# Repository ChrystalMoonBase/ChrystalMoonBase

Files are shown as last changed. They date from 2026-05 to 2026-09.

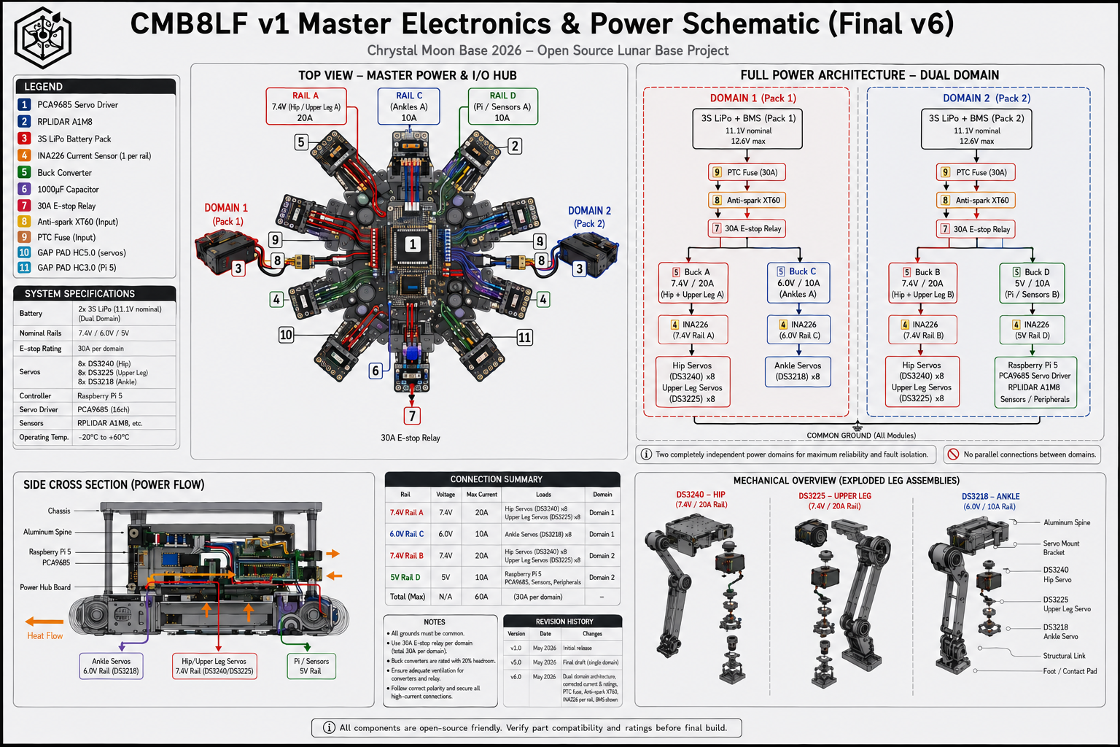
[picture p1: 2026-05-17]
systems/CMB8LF_v1/diagrams/CMB8LF-v1-Master-Schematic-Final-v6.png

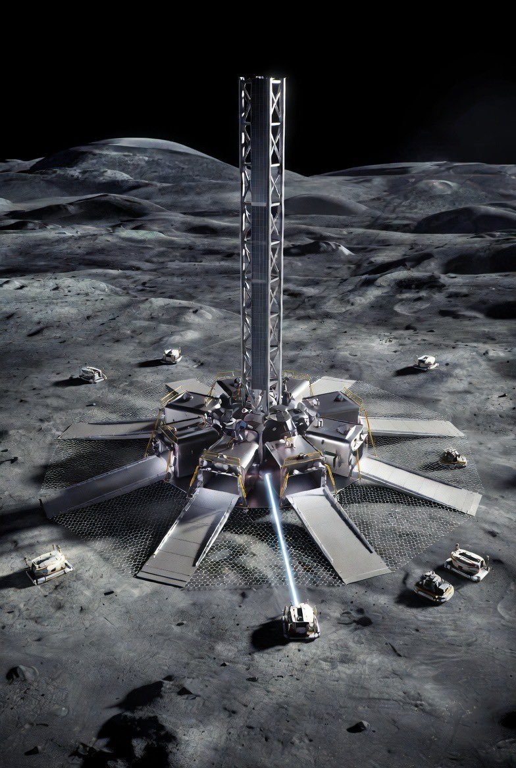
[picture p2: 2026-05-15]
public/assets/images/mastpod-render.png

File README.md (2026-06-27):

# Chrystal Moon Base
## Official Open-Source Repository

**A concept proposal for a permanent Moon base built from local lunar materials by autonomous robots.**
No flags. No patents. For all of humanity.

**Website:** https://chrystalmoonbase.com
**Licence:** Hardware: CERN-OHL-S-2.0 · Documents: CC0 · Software: Proprietary (not published)
**Status:** Phase 0 — Earth demonstrators (concept and planning stage)
**ESA OSIP:** Qualified — Open for Discussion · 2026

---

## What This Is

Chrystal Moon Base is an open-source concept for building a permanent human settlement on the lunar north pole (Peary Crater rim, 88.63°N) using:

- **Autonomous octopod robots** (CMB8LF-L1) — 16 robots powered by laser beamed from a ~35-metre solar mast
- **In-situ laser sintering** — fusing Peary highland regolith (anorthosite) into structural sintered glass-ceramic floors, walls, and dome foundations
- **600 m² roll-out CIGS solar system** — ~104–143 kW continuous power
- **Local material processing** — ~20 processing modules extracting glass, aluminium, oxygen, silicon, and (pending confirmed ice) water from the Moon
- **Multi-layer glass domes** — aluminium-reinforced, self-sealing habitats for permanent human residents
- **Maglev transport** — connecting all base facilities

> **Materials note:** Peary is highland / anorthosite terrain — aluminium-, silicon-, calcium- and oxygen-rich, but iron- and titanium-poor. Aluminium (not titanium) is the local structural metal. See `PEARY-MATERIALS-REFERENCE.md`.

---

## The Founder

**Berechja Kerkdijk**
Hegelsom, Limburg, Netherlands.
No PhD. No laboratory. No investors.
Just a man with a dream — researched and grounded in current science and technology.

---

## CMB8LF-S1 — Scale Prototype

The **CMB8LF-S1** (Chrystal Moon Base 8 Legged Freaks, version 1) is a 1:3.5 scale prototype of the CMB8LF-L1 lunar robot. It is the door that opens all other doors — a fully functional demonstrator that proves the concept physically.

**Key specifications:**
- 26× brushless BLDC motors with moteus r4.11 CAN controllers
- Distributed 22V power (25 independent battery nodes)
- Wave gait locomotion (maximum stability — 7 feet always grounded)
- Dual-laser palm: 808nm sinter + 976nm anneal (real glass powder sintering)
- 4-finger adaptive gripper: box grip / pincer / foot modes
- Bistable electromagnetic coupling (9 identical interfaces)
- All sensors in detachable head module
- Full vacuum compatibility (MoS₂ dry film · Si₃N₄ ceramic bearings · PEEK-CF)
- CAN bus internal · FSO laser communication external

**See:** `systems/CMB8LF_v1/`

---

## Repository Structure

```
foundation/
  governance/         CMB authority, tenant model, Earth relationship
  location/           Why Peary Crater — site selection and data
  philosophy/         Open-source principles, civilisation blueprint

media/                Pitch, technical, and vision one-pagers

roadmap/
  phase-0-earth/      Five Earth demonstrators (validation programme)
  phase-0.2-the-pod.md
  phase-1-foundation.md
  phase-2-the-city/
  phase-3-spaceport.md
  phase-4-beyond.md
  civilisation-blueprint/

systems/
  CMB8LF_v1/          ← Scale prototype robot (BUILD THIS FIRST)
    cad/              All 3D models (OpenSCAD) — open hardware
    docs/             BOM, assembly, shopping list
    diagrams/         Wiring, system overview
    (software is proprietary and kept in a separate private repository)
  robot-cmb8lf-l1/       Lunar robot concept specification
  sintering/          Laser sintering physics
  pod/                MAST-POD — mast, solar, laser, anchoring
  processing-modules/ All 13 resource extraction modules
  domes/              Habitat dome architecture
  life-support/       Atmosphere, water, food, radiation, gravity
  ai-and-monitoring/  Base AI, safety systems
  underground-network/Tunnels, maglev, emergency shelters
  surface-access/     Decontamination sequence

public/               Website source (chrystalmoonbase.com)
```

---

## Current Status

| Phase | Status |
|---|---|
| Phase 0 — CMB8LF-S1 prototype | **Active development** |
| Phase 0 — Earth demonstrators | Planning |
| Phase 0.2 — The Pod | Concept proposal |
| Phase 1+ | Long-term concept |

---

## How to Contribute

**Find an error:** Open a GitHub Issue.
**Improve a document:** Fork → edit → pull request.
**Build the prototype:** Follow `systems/CMB8LF_v1/README.md`
**You are an engineer:** Review the specifications. Find the problems. Say so clearly.

**Help us validate an open design question:** We are currently weighing an **integrated,
head-less robot** against the earlier **detachable-head** design, and we want engineering
input on whether we made the right call. See **`OPEN-DESIGN-INQUIRY-robot-head.md`**.

All contributors credited in `CREDITS.md`.

---

## Philosophy

The ISS proved that former rivals can build what neither could alone.
CERN proved that 23 nations can discover what one never would.
Chrystal Moon Base aspires to that same principle.

The Moon belongs to all of us.
This repository is our invitation to build it right.

---

## Contact

- **Email:** info@chrystalmoonbase.com
- **Website:** https://chrystalmoonbase.com
- **X:** [@chrystalbase](https://x.com/chrystalbase)

---

*No flags. No patents. No false promises.*
*Just a question worth asking honestly — and a Moon worth building together.*
🌙

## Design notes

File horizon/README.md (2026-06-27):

# CMB Horizon — speculative / far-future chapters

**Speculative / far-future chapters of Chrystal Moon Base.**
Deliberately separated from the hard CMB pillars (CMB8LF-S/L robots, MAST-POD, MRE
chain, gated-growth). Near-term feasibility is **not** claimed. Where something violates
a physical law, it is stated explicitly.

This folder collects the most exploratory CMB ideas. They are written to be *questioned
and corrected*, not believed. Two chapters so far:

1. **ISRU Cable Network & CMB8LF-B1 Tunnel-Mole** — linking the four Peary peaks.
2. **Hybrid Radiation Shielding (open question)** — could a superconducting magnet +
   passive layered dome ever help protect a habitat? Written as an honest open question;
   the most speculative item in the whole repo.

## Contents

```
horizon/
├── HORIZON_ISRU_cable_network.md          # chapter 1 (English, repo)
├── HORIZON_magnetic_shield_question.md     # chapter 2 — hybrid shield (THEORETICAL ONLY)
├── figures/
│   ├── mesh_overview.svg           # Fig.1 — 4 Pods + communication mesh
│   ├── worm_cross_section.svg      # Fig.2 — CMB8LF-B1 tunnel-mole, 2 zones
│   ├── electrical_schematic.svg    # Fig.3 — cable build-up + Pod-to-Pod line
│   └── factory_chain.svg           # Fig.4 — regolith→cable factory chain (F1-F4)
└── _werkversie_NL/                 # Dutch working copies (not for publication)
```

## Chapter 2 in one paragraph — Hybrid Radiation Shielding

Could an active superconducting magnet (bending charged cosmic-ray particles) paired with
a passive layered dome (catching the secondary neutrons the magnet cannot touch) ever
help shield a CMB habitat? The chapter establishes that this is a real, CERN/ESA/NASA
research line — but an **unsolved** one — and then honestly dismantles an earlier
over-optimistic draft: realistic dose reduction is **factor 2–3, not 99%**; the lunar
surface dose is ~380 mSv/yr (not 165); thick passive mass has **negative** returns past
~45 g/cm² due to secondary particles; YBCO (≈77 K) fits Peary's cold floors but MgB₂ does
not; and the ~20 GJ quench-protection problem is unsolved. The hybrid is the *right shape*
of an answer, but the specific numbers in the enthusiastic version did not survive
checking. Written explicitly as a question, inviting correction.

## Chapter 1 in one paragraph — ISRU Cable Network

The four *peaks of (near-)eternal light* on Peary's rim each carry an **energetically
independent Pod**. They are linked only for **communication/coordination** (not energy),
forming a self-healing mesh. This solves shadow downtime by *spreading locations*, with
no energy transported across the crater — which is physically impossible at the required
scale (130 kW over 100 km is 2–3 orders beyond the DARPA/China/Caltech state of the art;
diffraction is a physical law). Any cabling is made **on site** from regolith: aluminium
conductor (MRE/anorthite), glass/ceramic insulation (same regolith), laid underground by
the **CMB8LF-B1** — a new *Bore/Burrow* class robot that melt-bores a smooth glass duct
and lays the cable during production. One feedstock, three functions.

## Robot class registry

| Class | Meaning | Example | Status |
|---|---|---|---|
| S | Scale prototype | CMB8LF-S1 (1:3.5) | hard pillar |
| L | Lunar surface robot | CMB8LF-L1 (+ L1-Sinter/Dozer/Watcher) | hard pillar |
| **B** | **Bore / Burrow** | **CMB8LF-B1** (melt-boring tunnel-mole) | **HORIZON (speculative)** |

## Honesty note

This chapter is intentionally split into three feasibility categories:
**(1) impossible by physical law** (e.g. 100 km laser power beam),
**(2) possible but heavy/expensive** (e.g. hauling 100 km of cable from Earth),
**(3) possible and feasible** (e.g. ISRU cable + underground melt-bored duct).
All material/physics claims are sourced; see §10 of the main chapter.

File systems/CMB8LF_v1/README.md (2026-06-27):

# CMB8LF-S1 — Chrystal Moon Base 8 Legged Freaks
## Scale 1:3.5 · Vacuum-Rated · Brushless · CAN Bus · Full Revision v6

**Status:** Active development — build one leg at a time
**Author:** Berechja Kerkdijk
**Licence:** Hardware: CERN-OHL-S-2.0 · Software: Proprietary (separate private repo) · Docs: CC0

> **The prototype is the door.** Without a working robot, no door opens.
> Build it one leg per month. Two years if needed. But build it.

> **Parallel variant available.** A fully worked-out **head-less** version of this prototype
> exists at `../CMB8LF_v1_HL/` — same legs, same laser-palm, same brain, but with all sensing
> integrated into the body instead of a detachable head. It is kept build-ready so that if the
> open design question (`../../OPEN-DESIGN-INQUIRY-robot-head.md`) favours the head-less
> direction, no redesign is needed. This `CMB8LF_v1` folder remains the standard (with-head) build.

---

## What This Robot Does

- Walks on 8 legs using wave gait (7 always grounded — maximum stability)
- Sinters real glass powder / regolith simulant using dual lasers (808nm + 976nm)
- Grips objects in 3 modes: box grip · pincer · foot pad
- Operates in vacuum (MoS₂ dry film · ceramic bearings · no lubricants)
- Swaps its own legs with help from a second robot
- Communicates via laser (FSO) externally · CAN bus internally
- Runs 3-layer AI: Jetson Orin Nano strategic · Pico W coordination · RP2350 reflexes

---

## Specifications

| Parameter | Value |
|---|---|
| Scale | 1:3.5 |
| Legs | 8 (octopod) |
| Gripper legs | 2 (leg 1 + leg 2, front) |
| Joints | 26 (24 leg + 2 head) |
| Motors | 26× BLDC brushless |
| Motor controllers | 26× mjbots moteus r4.11 |
| System voltage | 22.2V (6S Li-Ion) |
| Battery nodes | 25 (distributed — one per segment) |
| Body battery | 4S 5000mAh LiPo |
| CAN bus speed | 1 Mbit/s |
| Gait | Wave gait (1 leg at a time) |
| Material structure | PEEK-CF |
| Bearing type | Si₃N₄ ceramic (vacuum-proof) |
| Lubrication | MoS₂ dry film only |
| Printer required | CreatBot PEEK-300 (primary) · Voron 2.4 + Rapido UHF or Intamsys FUNMAT HT (DIY alternatives) |
| Total cost estimate | ~€7.300 excl. printer |
| Build time | 10–14 months (one leg/month) |

---

## Build Order (one leg per month)

```
Month 1     Tools + printer + compute hardware
Month 2     Leg 3 (first standard leg — learn the system)
Month 3     Leg 1 (first gripper leg — laser palm)
Month 4     Leg 4
Month 5     Leg 2 (second gripper leg)
Month 6     Leg 5
Month 7     Leg 6
Month 8     Leg 7
Month 9     Leg 8
Month 10    Head module + all sensors
Month 11    Body + 9 coupling interfaces
Month 12+   Calibration · wave gait tuning · laser test · demo
```

---

## File Structure

```
CMB8LF_v1/
├── README.md               ← You are here
├── BOM_v6.md               ← Complete bill of materials
├── PRINT_SETTINGS.md       ← PEEK-CF print settings
├── VACUUM_PREP.md          ← Vacuum chamber preparation guide
├── SUPPLIER_MAILS_v6.md    ← Supplier contact templates
│
├── software/
│   ├── README.md
│   ├── main_v6.py          ← Pico W #1 — CAN master (start here)
│   ├── safety_pico.py      ← Pico W #2 — safety + web
│   ├── config_v6.py        ← All parameters and node IDs
│   ├── wave_gait_v6.py     ← Wave gait controller
│   ├── sinter_seq_v6.py    ← Laser sinter sequencer
│   ├── can_bus.py          ← CAN bus communication layer
│   ├── moteus_ctrl.py      ← moteus r4.11 controller interface
│   ├── rp2350_segment.py   ← Per-segment mini AI (runs on RP2350)
│   ├── laser_palm_v6.py    ← Laser palm driver (runs on palm RP2350)
│   ├── jetson_main.py      ← Jetson Orin Nano — strategic AI + navigation
│   └── web_v6.py           ← Web dashboard (runs on Pico W #2)
│
├── cad/
│   ├── CMB8LF_v1_vacuum_config.scad      ← Central dimensions (include first)
│   ├── CMB8LF_v1_leg_standard.scad       ← Standard leg (×6)
│   ├── CMB8LF_v1_leg_gripper.scad        ← Gripper leg (×2)
│   ├── CMB8LF_v1_palm_laser.scad         ← Laser palm assembly
│   ├── CMB8LF_v1_coupling_interface.scad ← Bistable magnetic coupling
│   ├── CMB8LF_v1_head_module.scad        ← Head with pan+tilt
│   ├── CMB8LF_v1_body_chassis.scad       ← Spider body
│   └── CMB8LF_v1_klipper_config.cfg      ← Printer config (Voron 2.4 DIY alt; CreatBot PEEK-300 uses its own slicer)
│
├── docs/
│   ├── CMB8LF_v1_BOM_vacuum.md
│   └── CMB8LF_v1_shopping_list.md
│
└── diagrams/
    ├── CMB8LF_v1_Wiring_Diagram.svg
    ├── CMB8LF_v1_Graphical_Overview.svg
    └── CMB8LF_v1_Lighting_Overview.svg
```

---

## I2C / CAN Bus Address Map

| Bus | Device | Address / Node ID | Notes |
|---|---|---|---|
| Jetson I2C | BNO055 IMU | 0x28 | Head |
| Jetson I2C | VL53L1X left | 0x29 | Head |
| Jetson I2C | VL53L1X right | 0x2A | Head |
| Jetson SPI | FLIR Lepton 3.5 | SPI0 | Head |
| Jetson UART | RPLIDAR A1M8 | UART | Head |
| Jetson CSI | Pi Camera 3 NoIR | CSI | Head |
| Jetson USB | USB-CAN (Canable) | — | CAN master |
| CAN | Leg 1 coxa moteus | Node 11 | Gripper leg L |
| CAN | Leg 1 femur moteus | Node 12 | Gripper leg L |
| CAN | Leg 1 tibia moteus | Node 13 | Gripper leg L |
| CAN | Leg 2 coxa moteus | Node 21 | Gripper leg R |
| CAN | Legs 3-8 | Node 3X-8X | Standard legs |
| CAN | Head pan moteus | Node 91 | Head |
| CAN | Head tilt moteus | Node 92 | Head |
| Pico W #2 I2C | INA226 ×4 | 0x44-0x47 | Power monitoring |
| Pico W #2 I2C | TMP117 body | 0x48 | Body temp |
| Pico W #2 GPIO | Hall sensors ×9 | GPIO 0-8 | Coupling status |

---

## Safety Rules — Always

1. **OD4+ laser goggles** rated for 808nm AND 976nm — always when lasers could activate
2. **E-stop button** within reach at all times during operation
3. **Never power lasers** unless gripper closed (hardware interlock enforces this)
4. **Never walk and sinter** simultaneously — these are separate modes
5. **MoS₂ only** — never oil, grease, or wet lubricant anywhere on the robot

---

## License

- Hardware designs: CERN-OHL-S-2.0
- Software: Proprietary — kept in a separate private repository (see `LEGAL-STRUCTURE.md` and `software/README.md`)
- Documentation: CC0

*CMB8LF-S1 · CC0 2026 · Chrystal Moon Base · No rights reserved*
*Multi-AI: Claude · ChatGPT · Meta · DeepSeek · Gemini · Human decisions: Berechja Kerkdijk*

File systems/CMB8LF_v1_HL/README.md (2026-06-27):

# CMB8LF-S1-HL — Head-Less Scale Prototype (parallel variant)

**Status:** Complete parallel design, ready to build if selected
**Author:** Berechja Kerkdijk
**Licence:** Hardware: CERN-OHL-S-2.0 · Software: Proprietary (separate private repo) · Docs: CC0

> **What this is.** A fully worked-out **head-less** version of the CMB8LF-S1 prototype,
> built and documented *in parallel* with the standard head variant (`../CMB8LF_v1/`). It
> exists so that, if the open design question in `OPEN-DESIGN-INQUIRY-robot-head.md` resolves
> in favour of the integrated/head-less direction, the build is **already finished** — schematics,
> CAD, BOM, firmware and all — and no months of redesign are needed. The decision becomes
> "pick variant A or B," not "now start designing B."

---

## The one difference

This variant changes **only the sensing/camera layer**. Everything else is identical to the
standard prototype:

| Subsystem | Standard `CMB8LF_v1` | This head-less `CMB8LF_v1_HL` |
|---|---|---|
| Sensors / cameras | In a **detachable front head** (pan/tilt module between leg 1 & 2) | **Integrated into the body** — work-sensing between the front legs + 360° awareness ring + override cameras. No head, no pan/tilt. |
| Working laser (sinter) | **In the front-leg palm** | **In the front-leg palm — UNCHANGED** |
| Legs (standard + gripper) | 8 legs, 3 DOF each | **Identical — shared** |
| Chassis / body shell | Spider PEEK-CF, 9th coupling = head | Spider PEEK-CF, **9th coupling removed/blanked**; sensor recesses added |
| CAN bus / moteus / motors | 26× RP2350, Pico W ×2, moteus | **Identical — shared** |
| Compute (brain) | Jetson Orin Nano in body | **Identical — shared (Jetson in body)** |
| Power / battery | Distributed rail | **Identical — shared** |
| Gait / kinematics | Wave gait, encoder-based | **Identical — shared** |

**Because only sensing changes, this variant does not duplicate the shared subsystems.** Where
a file would be byte-for-byte identical to the standard prototype, this folder **references the
shared base** instead of copying it — so the two variants cannot silently drift apart. Only the
files that genuinely differ are fully written out here.

---

## Files in this variant

**Fully worked out here (they differ):**
- `docs/HEADLESS_DESIGN.md` — the complete sensor-relocation design: what moves where, why,
  and how each sensor is protected.
- `CMB8LF_v1_HL_BOM.md` — full bill of materials (delta-marked against the standard BOM).
- `cad/CMB8LF_v1_HL_body_chassis.scad` — body shell with integrated sensor recesses and the
  9th (head) coupling blanked.
- `cad/CMB8LF_v1_HL_sensor_mounts.scad` — the new body-integrated sensor/camera mounts
  (replaces `head_module.scad`).
- `cad/CMB8LF_v1_HL_config.scad` — variant dimension overrides (sensor positions, recess sizes).
- `diagrams/CMB8LF_v1_HL_Wiring_Diagram.svg` — wiring for the relocated sensors/cameras.
- `diagrams/CMB8LF_v1_HL_Sensor_Layout.svg` — top/side view of where every sensor sits on the body.
- `software/sensors_headless.py` — sensor manager for the body-integrated layout + override feed.
- `software/config_headless.py` — pin map / sensor addresses for this variant.

**Shared with the standard prototype (do NOT duplicate — use the base files):**
- All leg CAD: `../CMB8LF_v1/cad/CMB8LF_v1_leg_*.scad`, `arm_leg_combined.scad`, `coupling_interface.scad`, `palm_laser.scad`
- All motion/control firmware: `../CMB8LF_v1/software/{gait,leg,moteus_ctrl,can_bus,rp2350_segment,safety,servo,wave_gait_v6}.py`
- Laser-palm firmware: `../CMB8LF_v1/software/laser_palm_v6.py`, `palm_spectroscopy.py`
- Print settings: `../CMB8LF_v1/PRINT_SETTINGS.md`, `CMB8LF-v1-PRINT_SETTINGS.md`
- Vacuum prep: `../CMB8LF_v1/VACUUM_PREP.md`
- Shared dimensions: `../CMB8LF_v1/cad/CMB8LF_v1_vacuum_config.scad` (this variant's config *includes* it and only overrides what changes)

---

## Why keep the laser-palm in the leg (unchanged)

The working laser stays in the front-leg palm exactly as in the standard build. This is
deliberate: the arm-legs already bring the laser precisely to the work point using
encoder-based positioning, and the palm already carries the close-range sinter/melt optics
and the palm spectroscopy. Moving the laser would change the proven leg design for no benefit.
The head-less change is *only* about where the **sensors and cameras** live — not the tool.

---

## Relationship to the L1 concept

This is the **scale prototype** expression of the head-less direction discussed for the
full-size L1 robot in `../robot-cmb8lf-l1/chassis.md` and `OPEN-DESIGN-INQUIRY-robot-head.md`.
Building it at prototype scale is how we test whether body-integrated sensing actually works
for precise close-up sinter/melt work before committing the lunar design.

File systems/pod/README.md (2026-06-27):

# Pod — Anchor System

**Chrystal Moon Base · Phase 0.2**
**Status:** Concept proposal — open question, not a flight specification.
**Licence:** CC0

---

## Selected design: Rooted Hybrid (v2.5)

The anchoring problem — how to attach a ~35-metre telescoping mast permanently to the lunar surface — was evaluated across four candidate concepts. After analysis, the **Rooted Hybrid** was identified as the strongest practical baseline.

**→ [mast-anchor-rooted-hybrid.md](./mast-anchor-rooted-hybrid.md) — canonical anchor specification**

### Why Rooted Hybrid

Three design principles make it the most defensible choice:

**Immediate stability** — A central titanium penetrator (120–150 kg) drives 0.5–0.8 metres into the regolith at landing. No waiting. The structure is mechanically locked from the first seconds.

**Permanent bonding** — Sintered regolith root plugs and beams, produced by the CMB8LF-L1 robots using the mast's own laser, chemically and mechanically fuse the anchor to the regolith over 6–8 weeks. Unlike pure mechanical anchors, this cannot loosen.

**Layered redundancy** — Neither the mechanical penetrator nor the sintered roots depends entirely on the other. If one system is weaker than expected due to regolith variability, the other provides backup. This is how serious aerospace structures are designed.

### Key open questions

| Question | Status |
|---|---|
| Regolith bearing capacity at Peary rim (88.63°N) | Requires Phase 0 ground testing |
| Sintering energy 8000 kWh/m³ — scalability to 0.25 m depth | Needs simulation + physical test |
| TRN landing precision — 26.5 m target zone on specific ridge | Engineering verification needed |
| Articulated shell segment reliability after cold soak at −150°C | Material and mechanism testing required |

---

## Archived alternatives

Three alternative anchor concepts were fully documented before the Rooted Hybrid was selected. They are preserved in full — not deleted — because the comparison itself is evidence of rigorous evaluation.

**→ [archive/](./archive/) — Spike, Pure Bloom, Adaptive Bloom**

The archive README explains the tradeoffs that led to the Rooted Hybrid selection.

---

## Files in this directory

| File | Description |
|---|---|
| `mast-anchor-rooted-hybrid.md` | **Canonical anchor design — use this** |
| `mast-overview.md` | Mast and solar curtain system description |
| `archive/` | Three evaluated-and-archived alternative anchor concepts |

---

**Repository:** [github.com/ChrystalMoonBase/ChrystalMoonBase](https://github.com/ChrystalMoonBase/ChrystalMoonBase)
**Contact:** info@chrystalmoonbase.com

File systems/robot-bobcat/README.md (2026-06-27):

# CMB Bobcat — Robotic Excavator / Dozer

> **Status:** concept. Role is concrete; exact dimensions, mass, and power are
> engineering decisions for professionals once real excavation volumes and the prototype
> are known. This document fixes *what it is and why*, not the final numbers.

> **Naming note:** a clean, plate-style code (type instantly readable from the code) will
> be assigned later when the whole robot family is renamed. For now: "CMB Bobcat".

---

## Role: the digger and ground-mover

The Bobcat is a **dedicated earth-moving machine** — a robotic equivalent of a compact
Bobcat-style loader. It does the two heavy ground tasks that are fundamentally different
from the octopod's "stand still and sinter" work:

- **Excavating** — digging trenches, foundations, the underground network, and
  (contingent on confirmed ice) ice-bearing regolith.
- **Dozing / grading** — pushing and levelling loose regolith, preparing flat ground for
  the octopods to sinter on.

Digging and pushing require **traction and brute force in one direction**, a completely
different body from a robot that must hold an eight-point stance to weld. That physical
difference — not specialisation for its own sake — is why the Bobcat is its own class.

---

## Why a separate machine (not an octopod tool-swap)

The octopod (CMB8LF) is a work platform: it must stand rock-still on uneven ground while a
laser arm does precision work. Excavation is the opposite — it needs to **drive force into
the ground** and move material in volume. Trying to do that on eight legs built for
stillness would compromise both tasks. The Bobcat is therefore a different *body for a
different physical reality*, the same logic that gives the transport bot and the cable-worm
their own forms. The "no specialists" principle still holds **within** the construction
fleet of octopods; the Bobcat is a different class, not a fourth specialist octopod.

---

## Locomotion: tracks, not legs (likely)

Excavators on Earth use tracks for a reason: they spread weight, grip loose ground, and
resist the reaction forces of digging. On loose lunar regolith and slopes, tracks are the
strong candidate — but wheels-on-frame or a hybrid are not ruled out. **Final locomotion
choice is for the professionals**, tested against real regolith behaviour. What is fixed:
it does not walk; it drives and pushes.

---

## How it fits the fleet

- **Works ahead of the octopods:** the Bobcat prepares and levels ground; the octopods
  then sinter it. Natural task ordering.
- **Feeds the ISRU chain:** excavated regolith is raw feedstock for the processing
  modules.
- **Shares the canister standard** (see transport-bot): excavated material can be loaded
  into standard canisters for the transport bot to move.
- **Redundancy by number, within its own class:** like the octopods, the answer to "what
  if one fails" is more than one — not in-field electronics repair.

---

## When it is needed (timeline)

- **Not strictly day one.** The very first task is the octopods proving they can walk and
  sinter (the swarm foundation). Heavy excavation comes once surface work is underway and
  the base goes underground.
- **Early, though:** ground levelling helps the octopods sinter sooner, so a Bobcat is an
  early-growth addition rather than a far-future one.

---

## Specifications — for the professionals

The following are deliberately **not fixed** here; they require excavation-volume data,
mass-budget analysis, and prototype testing:

- Size, mass, and track/drive design
- Digging force, bucket/blade volume, reach
- Power draw and how it is fed (laser beaming like the octopods? onboard? hybrid?)
- Thermal handling under sustained heavy load
- How many Bobcats per fleet (depends on total excavation workload)

What is fixed: **role** (dig + doze), **why separate** (force vs. stillness), **fleet
fit** (works ahead of octopods, feeds ISRU, shares canisters), and **redundancy by
number**.

---

## Open questions

1. Tracks vs. wheels vs. hybrid on real Peary regolith and slopes?
2. Power: beamed (like octopods) or onboard? Heavy continuous digging is power-hungry.
3. Does it also load canisters, or only loosen/push material for others to load?
4. How much of the octopod's proven subsystems (sensors, comms, autonomy stack) can it
   reuse to avoid designing a second robot from scratch?

*Engineers and mission planners are invited to review and improve this document.*

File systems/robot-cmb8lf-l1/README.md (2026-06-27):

# CMB8LF-L1 — Autonomous Octopod Construction Robot

**Chrystal Moon Base · Phase 0.2**
**Status:** Concept proposal — no prototype exists. Open question, not a specification.
**Kinematic reference:** [Robugtix T8](https://www.robugtix.com) — 8 legs, 3 DOF/leg, verified platform
**Licence:** CC0 (documents) · CERN-OHL-S-2.0 (hardware designs)

---

## Design philosophy: sixteen identical, fully capable

There are no specialists. There is no dependency between robots. Every CMB8LF-L1 is identical to every other CMB8LF-L1, and every CMB8LF-L1 can do everything.

This is not a choice driven by elegance. It is driven by reliability. On the Moon there is no repair crew. With sixteen identical chassis, loss of one robot means loss of one-sixteenth of capacity — nothing more. The other fifteen continue unchanged.

---

## Key specifications

| Parameter | Value | Notes |
|---|---|---|
| Mass | ~300 kg | Estimated |
| Legs | 8 × 3-DOF | T8 kinematic architecture |
| Configuration | 6 stance · 2 arm-legs | Front pair — each carries a separate module |
| Foot type | Snowshoe flat plate | 400 × 150 mm — no sinkage in 1/6 g regolith |
| Frame | Ti-6Al-4V | Titanium alloy structural skeleton |
| Armour | Mineral fibre (anorthosite) + MgAl2O4 ceramic | Multi-layer thermal and impact protection |
| Power | Laser beaming | GaAs PV receiver, quadrant beam tracking |
| Battery | Solid-state LiPON | One cell per leg segment — local motor power |
| Left arm module | Sintering laser | 10-20 cm compact unit, EPM-swappable |
| Right arm module | W-Re alloy forming tip | Direct regolith shaping, EPM-swappable |
| Heavy tool interface | EPM electropermanent magnet | less than 5 W pulse to lock, 0 W to hold |
| Temperature range | -180C to +130C | Full Peary crater rim operational envelope |
| AI system | Triple Modular Redundancy TMR | Fault-tolerant autonomous control |
| Degraded mode | 5-leg gait | On single leg failure — no mission abort |
| Dust sealing | Triple-ring brush NiC fibre | All joints and rotation interfaces |

---

## The two-arm system: melt and form

This is the core of what the CMB8LF-L1 does. Two arm-legs. Two functions. One continuous motion.

### Left arm — laser module

A compact laser unit (10-20 cm) connects to the left arm-leg via EPM. It melts lunar regolith to approximately 1100-1200 degrees C. The laser module is a swappable unit: if it fails, the robot walks to the tool rack, disconnects the old module, picks up a spare, and resumes in minutes.

### Right arm — W-Re forming tip

A tungsten-rhenium alloy tip connects to the right arm-leg via EPM. While the left arm melts the surface, the right arm presses, shapes, and holds the molten regolith as it cools from ~1200C toward ~800C. The result is a formed, smooth, solid surface.

In vacuum there is no convective cooling. Molten regolith in lunar vacuum cools significantly slower than on Earth, giving the forming tip time to work. At forming temperature its viscosity is comparable to thick syrup — a few newtons of steady pressure is enough to shape it. (Viscosity/temperature figures here are basalt-referenced; see the feedstock note below.)

This is, in essence, robotic glassblowing on the Moon — with melted regolith (anorthosite).

> **Feedstock note:** The ~1,200 °C figure is *basalt-referenced* (from published experiments and simulants). The actual Peary feedstock is highland anorthosite, which melts hotter (~1,550 °C), raising laser-energy demand and tightening forming-tip and cooling margins. See `systems/sintering/laser-sintering-physics.md` → "Melt Temperature — Basalt versus Highland Anorthosite".

**Why W-Re:**

| Property | Value | Significance |
|---|---|---|
| Melting point | above 3000C | Safe margin over molten regolith (~1,200 C basalt-ref / ~1,550 C anorthosite) |
| Ductility | W-25%Re: significantly higher elongation than pure W | Survives arm-leg impact loads without fracture |
| Magnetic | Non-magnetic | Does not attract electrostatically charged lunar dust |
| Chemical stability | No oxidation below 500-600C | In lunar vacuum: zero oxidation |
| Surface coating | HfC melting point 3958C | Reduces molten-regolith adhesion to the tip |

**Thermal isolation:** A ceramic thermal break (aerogel + ZrO2 standoffs) sits between the W-Re tip and the Ti-6Al-4V arm structure.

### If a module fails: detach and replace

Both the laser module and the W-Re forming tip connect via the same EPM interface. If either fails:

1. Robot walks to the tool rack
2. EPM pulse — module detaches
3. Robot picks up spare module from rack
4. EPM pulse — locked
5. Robot resumes

No other robot needed. No mission pause. Spare inventory: laser modules, W-Re tips, bulldozer blades, digger tools — all in the same rack, all using the same EPM interface.

### Two robots working together

One robot can operate both arms on a single patch. Two robots can also collaborate: one melts with its left arm while the second forms with its right arm on the same surface. This doubles throughput on critical sections and provides natural redundancy.

---

## All sensors integrated in the chassis

No sensor specialist. Every CMB8LF-L1 carries the full suite permanently:

- Terrain scanner — continuous surface mapping
- Temperature sensors — monitoring sintered surface temperature in real time
- Beam tracking photodiode — quadrant sensor for laser power alignment at 100 Hz
- Structural load sensors — in each leg segment
- Stereo cameras — on the main body

---

## Stability during arm operation

Six stance legs hold the robot steady while both arm-legs work.

**Snowshoe feet** — 400 x 150 mm flat plates distribute ground pressure. No sinkage even under arm reaction forces in 1/6 g regolith.

**Six-leg positioning** — 3 DOF per leg. All six splay wide, lower the centre of mass, and pre-load before arm contact.

**W-Re tip geometry** — the forming tip presses with controlled, predictable force. The HfC coating prevents sticking. The arm releases cleanly at any point in the forming cycle.

---

## Heavy tool operations (EPM-swapped)

When the robot needs to move large volumes of loose regolith or excavate tunnels, it swaps one or both arm modules for heavy tools:

- **[Bulldozer blade](./tools/bulldozer-blade.md)** — Al-Mg-Sc, 1.2 m x 0.4 m
- **[Digger tool](./tools/digger-tool.md)** — counter-rotating bucket drums (Phase 1.2+)

The swap is the same motion as swapping a laser module or forming tip. Walk to rack, EPM pulse, walk away.

---

## What this replaces

**Previous concept (archived):** Four specialist robot types — melter, all-rounder, temperature buddy, bulldozer. Specialist dependency.

**Current concept:** Sixteen identical chassis. Left arm melts. Right arm forms. EPM swaps anything. Nothing depends on a specialist.

---

## Open questions

| Question | Why it matters |
|---|---|
| Does molten regolith (anorthosite) adhere to HfC-coated W-Re? | Core feasibility of the forming tip |
| Optimal W-Re tip geometry for molten-regolith shaping | Flat press? Curved blade? Requires physical test |
| Thermal break performance under -150C to +1200C cycling | Ceramic standoffs must survive repeated thermal shock |
| Laser module thermal management in arm-leg | Heat routing within confined arm structure |
| Molten regolith cooling rate in lunar vacuum | Determines working window for the forming tip |
| LiPON battery after repeated thermal cycling | Leg segment power reliability |
| Sintering energy nominal 8000 kWh per cubic metre | Most uncertain number in the entire system |
| Regolith bearing capacity at Peary rim | Determines leg stance force limits |

---

## Directory structure

```
systems/robot-cmb8lf-l1/
├── README.md                         <- this file
├── tools/
│   ├── README.md                     <- EPM interface and spare parts
│   ├── bulldozer-blade.md
│   └── digger-tool.md
└── reference/
    └── kinematic-reference-t8.md
```

---

**Repository:** github.com/ChrystalMoonBase/ChrystalMoonBase
**Contact:** info@chrystalmoonbase.com

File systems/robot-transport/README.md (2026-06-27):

# CMB Transport Bot — Robotic Hauler

> **Status:** concept. Role is concrete; exact dimensions, mass, payload, and power are
> engineering decisions for professionals once real cargo volumes and the prototype are
> known. This document fixes *what it is and why*, not the final numbers.

> **Naming note:** a clean, plate-style code (type instantly readable from the code) will
> be assigned later when the whole robot family is renamed. For now: "CMB Transport Bot".

---

## Role: move (almost) anything from A to B

The transport bot is a **dedicated hauler**. Once the base starts producing and growing,
material has to be moved: sintered components, excavated regolith, harvested modules from
dead robots, spare parts from the garages, ice-bearing material, ISRU feedstock between
factories. The octopods *can* drag loads in a pinch, but they are work platforms, not
movers — hauling over the base's own (already sintered) flat paths is a different task.

Over prepared, sintered paths, **wheels are the logical choice** — exactly the point made
in the "why legs, not wheels" discussion: wheels are perfect for rolling over prepared
ground, which is precisely what the transport bot does. It does not work on loose slopes;
it runs on the roads the octopods have already laid.

---

## The key idea: a standard canister

The transport bot is designed around a **standard canister / container**, not around any
single cargo type. This is the shipping-container principle applied to the Moon:

- Everything that needs moving goes into the **same standard canister format**.
- The transport bot does not need to know *what* it carries — only *how to couple a
  canister*.
- The same canister can be handled by the **transport bot, the octopods, and the Bobcat**
  — one shared interface across the whole fleet.

Just as standard containers transformed logistics on Earth (one size, and suddenly
everything fits every truck, ship, and crane), a single canister standard means any
machine can pick up any load. This is the transport bot's most important design decision —
arguably more important than the bot's own body.

---

## Why a separate machine (not an octopod tool-swap)

Hauling cargo efficiently over flat sintered paths is a different physical job from
standing still to sinter. Wheels + a canister coupling are simpler, lighter, more
energy-efficient, and stable enough for this task — where the octopod's eight legs would
be overkill. Different body for a different physical reality; the "no specialists"
principle holds within the octopod construction fleet, and the transport bot is a separate
class.

**Fallback safety:** if every transport bot were to fail, the octopods can still haul
loads themselves (slower, less efficient). So the transport class makes the base *more
efficient* but is not a hard single-point dependency — the construction class can fall
back on itself.

---

## How it fits the fleet

- **Runs on octopod-built roads:** transport follows construction. It needs sintered flat
  paths, which the octopods produce as they work.
- **Connects the chain:** Bobcat excavates → canister → transport bot moves it → ISRU
  module or build site. The canister standard ties it together.
- **Redundancy by number, within its own class.**

---

## When it is needed (timeline)

- **Not day one.** Early on there is little to move and few paths to move it over. The
  swarm foundation (octopods walking and sintering) comes first.
- **Grows in with the base:** as sintered paths and production volume appear, the
  transport bot becomes worthwhile. A growth-stage addition.

---

## Specifications — for the professionals

Deliberately **not fixed** here; they require cargo-volume data, mass-budget analysis, and
prototype testing:

- Size, mass, wheel/drive design, payload capacity
- The exact canister standard (dimensions, coupling mechanism, how it locks)
- Power draw and how it is fed (beamed / onboard / hybrid)
- How many transport bots per fleet (depends on cargo workload and path network size)

What is fixed: **role** (haul anything via standard canisters), **wheels over sintered
paths**, the **canister standard as the core idea**, **fleet fit**, and **octopod
fallback**.

---

## Open questions

1. Canister dimensions and coupling: what single standard serves regolith, parts,
   modules, and ice equally well?
2. Power over distance: beamed power works near the mast; long hauls may leave beam range
   — onboard battery, swappable canister-batteries, or path-side charging?
3. Does the transport bot self-load, or do octopods/Bobcat load the canisters onto it?
4. How much of the octopod's proven subsystems (sensors, comms, autonomy) can it reuse?

*Engineers and mission planners are invited to review and improve this document.*

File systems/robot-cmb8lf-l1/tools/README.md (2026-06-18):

# CMB8LF-L1 Tool Interface — EPM Standard & Spare Parts

**Chrystal Moon Base · Phase 0.2**
**Licence:** CC0

---

## What the EPM rack holds

Every CMB8LF-L1 tool — including the arm modules themselves — connects via the same EPM interface. The rack in each garage holds everything:

| Item | Type | Phase | Purpose |
|---|---|---|---|
| Sintering laser module | Arm module (left) | 0.2 | Melts regolith to ~1200C |
| W-Re forming tip | Arm module (right) | 0.2 | Shapes and smooths molten regolith |
| Bulldozer blade | Heavy tool | 0.2 | Grades loose regolith |
| Digger tool | Heavy tool | 1.2+ | Excavates underground tunnels |

Spares of the laser module and W-Re tip are stored alongside the heavy tools. Same rack. Same EPM connection. Same swap procedure.

---

## The EPM interface

| Parameter | Value |
|---|---|
| Activation energy | less than 5 W for less than 1 second |
| Hold power | 0 W — permanent magnet holds without power |
| Release energy | less than 5 W for less than 1 second |
| Moving parts | None |
| Fail mode | Locked — module cannot accidentally drop |

---

## Swap procedure (any module)

1. Robot walks to tool rack
2. EPM pulse — module detaches
3. Robot aligns arm-tip to replacement module on rack
4. EPM pulse — locked
5. Robot resumes work

No second robot. No human. No mission pause.

---

## Two-arm operation

The two arm-legs operate independently. In standard sintering mode:

- **Left arm:** laser module active — melts the surface
- **Right arm:** W-Re forming tip active — presses and shapes the melt

When heavy physical work is needed, one or both arm modules are swapped for the blade or digger. The laser and forming tip go back on the rack while the heavy tool is in use. When the grading or excavation is done, the robot picks its arm modules back up.

---

## What is NOT an EPM swap

All sensors (terrain scanner, temperature sensors, cameras, photodiodes, structural load cells) are permanently integrated into the chassis body. They never swap. They never go on the rack.

---

## Compatibility

The W-Re forming tip and the sintering laser module both use the same EPM mounting geometry. A robot with two forming tips or two laser modules is mechanically possible — though the standard configuration is one of each.

---

**Parent:** [../README.md](../README.md)
**Repository:** github.com/ChrystalMoonBase/ChrystalMoonBase

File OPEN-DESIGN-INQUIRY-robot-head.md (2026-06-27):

# Open Design Inquiry — Does the robot need a "head" at all?

**Status: active design direction, seeking engineering validation.**
**We are taking the lead with an integrated (head-less) concept, but we are explicitly
asking: did we make the right call, or should we step back to the detachable-head design?**

This is a question-led document in the spirit of the project: we would rather show the
open question honestly and invite correction than present a frozen decision. If you are an
engineer reading this — robotics, field robotics, space hardware, autonomy — your input on
this specific trade-off is genuinely wanted.

---

## The question in one line

Should each CMB8LF robot have a **distinct sensor head** (mounted at the front, detachable
like a leg), or should we **drop the head entirely** and integrate everything into the
body + legs?

---

## How we got here

The earlier design gave each robot a **head**: a front-mounted unit (spider position),
carrying the sensors and the working-laser optics, attached through the same universal EPM
coupling as the legs — so it could be swapped or harvested like a leg. (See the "Previous
concept" note in `systems/robot-cmb8lf-l1/chassis.md` and the `head-*.md` files.)

While reviewing the design we questioned a basic assumption: *is a "head" a real
engineering need, or is it a human/animal image we projected onto a machine?* A spider's
head is not a detachable add-on — it is fused with the body. A self-driving car has no
head — its sensors are distributed around the chassis. That reframing led to the current
direction.

---

## The direction we are now taking (and want validated)

**Drop the separate head. Integrate sensing into the body and legs.** Concretely:

1. **No detachable head.** Body + legs as one unit, like a real spider. This removes a
   coupling that can fail, a moving part, a dust-entry point, and a component that can be
   lost.

2. **The brain stays deep in the body.** Critical compute (the Jetson-class strategic AI)
   lives in the protected three-layer body core, never in an exposed, moving part. Putting
   costly hardware in the most exposed place would raise its failure rate and lose it if
   that part is damaged.

3. **"Measuring" is not "seeing."** For autonomous work the robot does not need eyes:
   - It knows where its arm-legs are from **joint encoders** (proprioception), not from
     looking at them.
   - It knows whether a sinter/melt is good from **thermal + spectroscopic measurement**,
     not from a camera view.
   - It builds a spatial map from **LiDAR / ranging**, not from human-style vision.

4. **Two distinct sensing needs, separated by function:**
   - **Targeted work-sensing — between the front legs.** Where the arm-legs do the
     sinter/melt work, downward/forward-looking measurement sensors watch the work zone
     directly.
   - **360° awareness — around the body.** Distributed fixed sensors around the chassis
     give all-round situational awareness (navigation, obstacles, other robots). No single
     moving head can cover 360° at once; distributed sensors can.

5. **A live camera feed is still required — but for the human, not the robot.** Every
   robot must support **override by a CMB engineer**. A human cannot override on encoder
   angles and spectra alone; they need a human-interpretable image. So each robot carries
   camera(s) feeding the work zone **plus** surrounding cameras, so an engineer can assess
   the whole situation before acting. Because of the ~2.6 s round-trip delay, this is for
   **situation assessment and re-tasking, not real-time joysticking** — which lowers the
   feed's latency requirements.

---

## What this buys us, and what it costs

**Gains:** fewer failure points (no head coupling, no head-swap mechanism), no
head-as-moving-part, better-than-a-head 360° coverage from distributed sensors, brain kept
in the safest place, lighter and simpler front end.

**Costs / things we give up or must solve:**
- We lose a *detachable* head that could be harvested from a dead unit. (Legs and
  arm-modules remain harvestable; is that enough redundancy?)
- Sensors that used to sit on a movable head are now fixed — we rely on distributed
  coverage + the robot turning its body instead of panning a head.
- **Open sub-question (unsolved):** the work-sensing between the front legs looks straight
  at intense heat, laser glare, and out-gassing/spatter from the melt zone — the most
  hostile spot for a sensor. How best to protect it (replaceable/closable window, oblique
  off-axis mounting, time-sharing while the laser is at full power)? We have deliberately
  **not** fixed this yet.

---

## The validation question for engineers

We are asking, plainly:

1. **Is dropping the head the right call** for a field robot doing autonomous lunar
   sinter/melt construction — or are we over-rotating on "no human assumptions" and
   throwing away a genuinely useful degree of freedom?
2. **Is encoder-based proprioception + distributed fixed sensing** truly sufficient for
   this kind of precise, close-up manipulation work, or does practice demand an
   articulated sensor platform after all?
3. **How would you protect the work-zone sensor** facing the melt? (The open sub-question
   above.)
4. If you would **step back to the detachable head**, what is the deciding reason?

Honest "you got this wrong because…" answers are the most useful kind. The full design is
open (`github.com/ChrystalMoonBase`, `chrystalmoonbase.com`); hardware under CERN-OHL-S-2.0,
docs under CC0.

> **Note:** the head-less direction is not just a sketch — a **complete parallel prototype
> variant** is already worked out at `systems/CMB8LF_v1_HL/` (BOM, CAD, schematics, firmware).
> So whichever way this resolves, the build is ready: it is a choice between two finished
> designs, not a request to start designing the alternative.

---

*This document records a design direction under active consideration. It is intentionally
not yet propagated into the full build documents; `chassis.md` now leads with the
integrated concept and references the superseded detachable-head design, but the older
`head-*.md` files are retained (with superseded banners) so the full history of the
decision stays visible.*

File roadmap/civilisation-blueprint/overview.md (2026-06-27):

# Civilisation Blueprint — Overview
## Chrystal Moon Base

**Status:** Long-term vision document  
**Licence:** CC0

---

## Summary

The Moon is a world of 38 million square kilometres. A single base is a camp. A civilisation is many specialised settlements connected by transport and communication, each located where the Moon makes something possible.

This section describes the four proposed provinces of a potential lunar civilisation — not a plan, but a direction based on the Moon's own geography.

---

## The Four Provinces

| Province | Location | Proposed Role |
|---|---|---|
| Solar Capital | Peary Crater Rim, 88.63°N | Power generation, first settlement |
| Water Treasury | South Polar Cold Traps, ~89.5°S | Ice extraction, propellant production |
| Gateway Plains | Equatorial Near-Side | Earth-Moon spaceport |
| Bridge to Mars | Far-Side Mare | Deep-space departure |

---

## Document Index

| Document | Description |
|---|---|
| peary-solar-capital.md | North pole province detail |
| south-pole-water-treasury.md | South pole province detail |
| equatorial-spaceport.md | Equatorial province detail |
| farside-departure-gate.md | Far-side province detail |

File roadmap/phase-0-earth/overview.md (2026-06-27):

# Phase 0 — Earth Demonstrators Overview
## Chrystal Moon Base — Validation Programme

**Status:** Planning stage — no hardware exists yet  
**Licence:** CC0

---

## Purpose

Before anything goes to the Moon, everything must work on Earth.

Phase 0 is a ground-based validation programme consisting of five demonstrators. Each demonstrator targets a specific technology or system that the Phase 0.2 Pod concept depends on. Each produces honest, publishable results — whether positive or negative.

---

## The Five Demonstrators

| # | Name | What It Tests |
|---|---|---|
| D1 | Laser Sintering | Can lunar regolith simulant be laser-sintered to structural quality? |
| D2 | Laser Power Beaming | Can laser power be delivered to a moving robot at the required efficiency? |
| D3 | Robot Locomotion | Can a CMB8LF-L1 prototype operate reliably in simulated lunar conditions? |
| D4 | Swarm Coordination | Can 2–4 robots coordinate autonomously to sinter a defined area? |
| D5 | Full Integration | Can all systems operate together in a single test? |

---

## Estimated Cost and Timeline

Total programme cost is **not yet fixed.** Early estimates varied too widely to publish a
single honest figure, and a credible per-demonstrator breakdown still has to be worked out
before any headline number would mean anything. The timeline runs across roughly 3–5 years
for the full five-demonstrator programme, but — like the build-time of the base itself —
the real pace will sharpen as each demonstrator returns actual data.

Crowdfunding alone will not cover this. The goal of Phase 0 crowdfunding is to fund Demonstrator 1 and to create a credible public record of serious intent that can open conversations with research institutions and space agencies.

---

## Document Index

| Document | Description |
|---|---|
| demonstrator-1-sintering.md | D1 protocol and success criteria |
| demonstrator-2-laser-power.md | D2 protocol and success criteria |
| demonstrator-3-robot-locomotion.md | D3 protocol and success criteria |
| demonstrator-4-swarm-logic.md | D4 protocol and success criteria |
| demonstrator-5-full-integration.md | D5 protocol and success criteria |

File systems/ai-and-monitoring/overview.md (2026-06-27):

# AI and Monitoring — Overview
## Chrystal Moon Base

**Status:** Concept proposal  
**Licence:** CC0

---

## The Role of AI in the Base

The AI monitoring system is the nervous system of the base. It watches everything, remembers everything, and alerts immediately when something is wrong.

This is not surveillance. It is the minimum viable safety architecture for an environment where a small failure can cascade into a life-threatening emergency faster than any human could detect and respond unaided.

The AI does not make governance decisions, does not control residents' behaviour, and does not override human judgment on non-safety matters. Its domain is the physical state of the base: pressure, temperature, atmosphere, structural integrity, power, water, robot status, and any parameter that could affect the survival of residents.

---

## Three AI Layers

**Layer 1 — Robot AI (distributed, onboard each robot):**
Real-time control of individual robot locomotion, tool head operation, and local fault response. See `systems/robot-cmb8lf-l1/ai-onboard.md`.

**Layer 2 — Construction AI (mast-based computer):**
Swarm coordination, construction planning, quality control aggregation, power delivery management. See `systems/robot-cmb8lf-l1/swarm-logic.md`.

**Layer 3 — Base AI (distributed across base network):**
Overall base monitoring, life support management, safety alert system, data relay to Earth. This document.

---

## Documents

| Document | Description |
|---|---|
| base-wide-monitoring.md | What is monitored and how |
| safety-systems.md | Emergency detection and response |
| privacy-policy-on-base.md | What is monitored where |
| data-relay-to-earth.md | Earth communication and oversight |

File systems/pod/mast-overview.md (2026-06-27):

# The MAST-POD Mast — Overview
## Chrystal Moon Base — Phase 0.2 Concept

**Status:** Concept proposal  
**Licence:** CC0

---

## Purpose

The mast is the central infrastructure element of the Pod. It serves three simultaneous functions:

1. **Power generation** — two roll-out CIGS solar film arms on the mast generate ~104–143 kW of continuous electrical power
2. **Power distribution** — five Beam and Sensor Modules (BSMs) on the mast deliver this power as a laser beam to working robots up to 2+ km away
3. **Communications** — a Ka-band antenna at the mast top maintains continuous contact with Earth

Everything else in the Pod concept depends on the mast being operational. If the mast fails to deploy, the mission ends before it begins. Mast deployment reliability is therefore the highest priority single engineering challenge in the Phase 0.2 concept.

**Two hard mission-enders, not one.** The mast shares its make-or-break status with the **bloom deployment** (the unfolding of the Pod's leaves; see `pod-bloom-deployment.md`). These are the two failures with no recovery path:
- *Mast fails to deploy* → no power beaming → the fleet cannot be sustained.
- *Pod lands intact but the bloom does not open* → the robots stay enclosed and unpowered, can never be activated, and cannot solve the problem themselves because they are trapped inside. This is at least as critical as the mast, possibly more so.

A **temporary** mast interruption is survivable: every robot carries a charged onboard battery reserve, so a short power-beaming gap does not immediately end operations — the fleet can bridge it on its own cells. What cannot be bridged is a *deployment* failure (mast or bloom) that prevents the system from ever starting. What happens after a total deployment failure — a crewed rescue, or a second Pod funded from revenue by then — is deliberately left open: it depends on data (partner valuation, revenue) that does not yet exist, so it is honestly marked as mission-end rather than given a fictional contingency.

---

## Physical Description

The mast is a 5-segment telescoping structure of Toray M55J carbon-fibre reinforced polymer with cyanate ester resin matrix. This material was selected for its stiffness-to-mass ratio, thermal stability across the lunar surface temperature range (−200°C to +130°C), radiation resistance, and minimal outgassing in vacuum.

**Stowed configuration:** The 5 segments are nested inside each other — the innermost (smallest diameter) at the top, the outermost (largest diameter) at the bottom, like a collapsed telescope. Total stowed height fits within the Pod upper section, within Falcon Heavy payload fairing constraints.

**Deployed configuration:** Each segment extends and locks sequentially, driven by a single Dyneema tension band running through all segments from a drive motor at the base. Total deployed height: approximately 35 metres.

> **Open engineering question:** A 6th segment has been discussed. Whether a 6th segment is structurally viable and adds meaningful value is an open question for qualified engineers. The current baseline is 5 segments / ~35 metres.

**Segment locking:** A passive collet mechanism at each segment interface locks automatically when the segment reaches full extension. No active locking is required — the collets engage mechanically under the tension of the Dyneema band. This eliminates a class of potential failures at the cost of making deliberate retraction impossible, which is acceptable since the mast is not designed to be retracted.

**Rotation system:** The entire mast rotates in azimuth on a magnetically levitated bearing (hybrid AMB/PMB) to track the sun continuously. This keeps the CIGS solar arms oriented perpendicular to incoming sunlight throughout the ~89% illuminated lunar year at Peary latitude.

**Why the rotating bearing survives lunar dust — by location, not just by type.** Lunar dust (fine, abrasive, electrostatically charged) is the classic enemy of any moving mechanism, so the bearing's dust strategy is deliberate and layered:

1. **Contactless by principle.** A magnetically levitated bearing has no rubbing mechanical surfaces in its load path — the mast floats on a magnetic field. There is no contact interface for dust to grind between, which removes the single worst failure mode that a conventional roller or sleeve bearing would have on the Moon.

2. **Placed inside the dust-controlled zone.** The bearing sits at the mast base, *within* the Vectran dust-containment skirt formed by the deployed bloom (see `pod-bloom-deployment.md`). That skirt is specifically there to exclude regolith dust from the working area around the pod base — so the bearing is not exposed to the open surface dust environment at all; it operates inside the protected footprint.

3. **Ringed by the garages.** The 8 robot garages are arranged around the pod base, forming an additional physical barrier between the bearing region and the surrounding terrain. They block line-of-sight dust transport (thrown by robot movement or electrostatic transport) toward the rotation axis.

Together these mean the bearing is protected three ways: it has no contact surface to foul, it lives inside the bloom's dust skirt, and it is shielded by the garage ring. (Note: the ~9 m solar arms and their ~24 m horizontal span sit high on the mast and are a separate matter from the dust skirt at the base — the skirt protects the base/bearing, not the elevated solar curtain.)

**Remaining honest open questions:** even a contactless bearing is not automatically dust-proof. Its position sensors, the control electronics, and the gap between rotating and fixed structure can still admit fine or charged dust over years of operation. A labyrinth or active seal at the rotation gap, and dust-tolerant sensor placement, remain open engineering questions for Phase 0 — the architecture reduces the dust *reaching* the bearing, but long-duration sealing of the gap itself must still be validated.

---

## Solar Power System

Two roll-out CIGS thin-film solar arms extend horizontally from the mast, one on each side.

| Parameter | Value |
|---|---|
| Solar film technology | CIGS thin-film (roll-out) |
| Total solar area | 2 × 9 m × 30 m = **600 m²** |
| Solar constant at Moon | ~1,361 W/m² (varies ~1,321–1,413/yr) |
| Conservative efficiency | 15.7% → **~104 kW** continuous |
| Optimistic efficiency | 21.5% → **~143 kW** continuous |
| Illumination availability | ~89% of lunar year at Peary rim |

These are estimates based on published CIGS efficiency ranges. Actual output depends on film degradation under UV and particle radiation, dust accumulation rate, pointing accuracy, and thermal effects. All are open engineering questions.

---

## Beam and Sensor Modules (BSMs)

Five BSMs are pre-mounted on the mast — one per segment — at approximately 7, 14, 21, 28, and 35 metres height. Each BSM:

- Receives electrical power from the solar arms
- Converts it to a directed laser beam (~10–20 kW class diode laser)
- Tracks a moving robot receiver autonomously
- Delivers usable power to the CMB8LF-L1 robot at up to 2+ km range

Multiple BSMs can operate simultaneously, powering multiple robots at once. If one BSM fails, the others continue operation.

---

## Deployment Sequence

1. Pod lands autonomously at selected high-illumination peak on Peary Crater rim
2. Pod stabilises and anchors (see Anchoring section)
3. Mast base motor activates, pulling Dyneema tension band
4. Innermost (top) segment rises first; collet locks at full extension
5. Sequence continues upward until all 5 segments are locked
6. CIGS solar arms, rolled around the mast during transit, unfurl as segments extend
7. Ka-band antenna at mast top deploys last
8. BSMs activate after solar power is confirmed
9. Garage doors open; CMB8LF-L1 robots walk out

Estimated deployment time: 2–4 hours. Deployment is slow and controlled — rapid deployment risks dynamic loads that could damage the structure in lunar vacuum and 1/6 g.

---

## Anchoring

After extensive evaluation of four anchor concepts (Spike, Pure Bloom, Adaptive Bloom, Rooted Hybrid), the **Rooted Hybrid** has been selected as the baseline design.

The Rooted Hybrid combines:
- An initial mechanical spike for immediate landing stability
- Expanding anchor elements that engage the regolith progressively
- A hardened sintered-regolith foundation sintered by the CMB8LF-L1 robots around the base over the first operational days

This approach provides immediate stability at landing while building toward permanent anchorage as construction proceeds. It is the most resilient of the four variants against unknown surface conditions at the specific landing site.

Full specification: [`systems/pod/mast-anchor-rooted-hybrid.md`](mast-anchor-rooted-hybrid.md)

---

## Key Open Engineering Questions

| Question | Why it matters |
|---|---|
| Mast deployment dynamics in lunar vacuum and 1/6 g | Thermal cycling stress on collet locks; dynamic loads during extension |
| BSM pointing accuracy over 2+ km | Beam divergence limits vs. receiver panel area on robot |
| CIGS film degradation rate | UV, particle radiation, micrometeorite flux over multi-year mission |
| Mast structural resonance | Solar wind particle pressure and thermal expansion cycles |
| Regolith bearing capacity at exact landing site | Determines anchor spike penetration depth and bloom engagement |

---

## Key Documents

| Document | Description |
|---|---|
| [`mast-solar-curtain.md`](mast-solar-curtain.md) | CIGS solar arm — power generation detail |
| [`mast-bsm-beam-sensor-module.md`](mast-bsm-beam-sensor-module.md) | BSM — laser power delivery detail |
| [`mast-anchor-rooted-hybrid.md`](mast-anchor-rooted-hybrid.md) | Anchor system — Rooted Hybrid (selected) |

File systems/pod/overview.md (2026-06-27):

# The Pod — Phase 0.2 Overview
## Chrystal Moon Base — First Lunar Mission Concept

**Status:** Concept proposal — feasibility not yet demonstrated  
**Author:** Berechja Kerkdijk  
**Licence:** CC0  
**Last updated:** 2026

> Every number in this document is an estimate based on publicly available data and physics. This is a concept sketch, not an engineering specification. If you find an error, please open an issue or submit a correction. That is the entire point of publishing this openly.

---

## What the Pod Is

The Pod is the proposed first physical mission of Chrystal Moon Base to the lunar surface. It is a single launch — one Falcon Heavy rocket — carrying everything needed to begin autonomous construction of a sintered regolith floor on the rim of Peary Crater at the lunar north pole.

The Pod does not carry humans. It does not need to return. It is intended to land, deploy, and operate indefinitely — for as long as the sun shines on the Peary rim, which is approximately 89% of the year.

---

## Contents

| Item | Quantity | Notes |
|---|---|---|
| CMB8LF-L1 octopod robots | 16 | 2 per garage, fully integrated sensors |
| Telescoping mast | 1 | Toray M55J CFRP, 5 segments, stowed ~9.7 m, deployed ~35 m |
| Magnetic rotation bearing | 1 | AMB/PMB — frictionless azimuth tracking |
| CIGS roll-out solar film | 1 | ~600 m² (2 arms × 9 m × 30 m), vertical, azimuth-tracking |
| Laser power beaming system | 1 | 10–20 kW class diode laser |
| Beam and Sensor Modules (BSM) | 5 | One per segment, at ~7 / 14 / 21 / 28 / 35 m |
| Ka-band communications antenna | 1 | Mounted on mast top (segment 5) |
| Base computer and power electronics | 1 | In central base plate |
| Garages | 8 | 2.0 m × 2.0 m × 1.5 m each, 2 robots per garage |

> **Why 16 robots?** The figure is derived from the Pod's own geometry, not chosen
> abstractly: the Pod carries **8 garages**, each sized to hold **2 robots**, giving 16.
> The number of garages, in turn, is bounded by what is plausibly achievable in mass and
> volume for a single lunar delivery. So 16 is an honest first estimate set by "how many
> robots fit and can be landed," **not** by a calculation of how many the build needs. The
> definitive fleet size — and whether early construction is faster with more, smaller
> robots or fewer, larger ones — is an **engineering decision for a later phase**, to be
> settled once real on-Moon sintering and digging rates are known.

---

## Physical Description

| Parameter | Value |
|---|---|
| Pod outer shape | Cylindrical (octagonal inner frame) |
| Pod diameter | ~4.6 m |
| Pod height (stowed, fairing) | ~11 m |
| Base plate | 1.0 m thick Al-Li 2099 isogrid, ⌀4.6 m |
| Base plate systems | Thrusters, fuel tanks, levelling actuators, avionics |
| Fuel | MMH/NTO hypergolic — spontaneous ignition, no ignition system needed |
| Levelling | 8 electromechanical linear actuators, ±0.5 mm precision |
| Bloom petals | 8 × honeycomb sandwich panels, Vectran cloth between petals |
| Garages | 8 × 2.0 m × 2.0 m × 1.5 m — 2 robots each |
| **Total launch mass (excl. robots)** | **~4,200 kg** |
| Falcon Heavy TLI capacity | ~15,000 kg |
| **Mass margin** | **~10,800 kg** |

---

## Power Budget

| Parameter | Conservative | Optimistic |
|---|---|---|
| Solar film area | 600 m² | 600 m² |
| Cell type | CIGS thin-film | CIGS thin-film |
| Cell efficiency | 15.7% | 21.5% |
| Solar constant | ~1,361 W/m² | ~1,361 W/m² |
| Annual availability | ~89% | ~89% |
| System losses | ~10% | ~10% |
| **Continuous power** | **~104 kW** | **~143 kW** |
| Laser optical output | ~10–15 kW | ~10–15 kW |
| Power surplus / battery charging | ~64 kW | ~103 kW |

---

## Operational Radius

The laser power beaming system is estimated to reach robots within **2+ km** from the mast base. In lunar vacuum there are no atmospheric losses — range is limited by BSM pointing geometry and robot receiver panel area. The AI selects the optimal BSM for each robot based on its current position. Robot receiver panels tilt automatically to optimise angle of incidence.

---

## Mass Budget Summary

| Component | Mass (kg) |
|---|---|
| Central base plate (Al-Li isogrid, incl. motors, tanks, actuators) | 1,200 |
| 8 bloom petals (honeycomb sandwich, incl. hinges and Vectran cloth) | 1,200 |
| 8 garages (structural, empty) | 400 |
| Magnetic rotation bearing (AMB/PMB) | 100 |
| Telescoping mast (5 segments, Toray M55J CFRP) | 200 |
| Arms, pulleys and film deployment mechanism | 100 |
| CIGS solar film (~600 m²) | 110 |
| Landing fuel and fluids | 600 |
| Avionics, cabling, communications, margin | 290 |
| **TOTAL (excl. robots)** | **~4,200 kg** |

*Robots and their systems are additional mass within the ~10,800 kg margin.*

---

## Document Index

| Document | Description |
|---|---|
| pod-bloom-deployment.md | Bloom petal deployment and dust containment |
| mast-overview.md | Mast architecture, segments, magnetic bearing |
| mast-solar-curtain.md | CIGS roll-out film — arms, deployment, power |
| mast-bsm-beam-sensor-module.md | BSM design and laser power delivery |
| mast-anchor-rooted-hybrid.md | Mast anchor — Rooted Hybrid (preferred; only anchor variant currently written) |
| laser-system.md | Laser power beaming architecture |
| power-budget.md | Full power budget analysis |

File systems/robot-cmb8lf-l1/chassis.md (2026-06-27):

# CMB8LF-L1 Chassis
## Chrystal Moon Base — Robot System Concept

**Status:** Concept proposal — not yet prototyped  
**Author:** Berechja Kerkdijk  
**Licence:** CC0

> This document describes the founder's vision for the CMB8LF-L1 chassis in detail. Engineering decisions — materials, exact dimensions, specific mechanisms — remain open for expert input. The vision sets the direction. Engineers determine the execution.

---

## Design Philosophy

The chassis is the structural and computational core of the CMB8LF-L1. Every design decision follows three principles:

1. **Materials from the Moon** — no material may be used in the chassis that cannot eventually be sourced from lunar resources. This means no carbon-fibre reinforced polymer (CFRP), no exotic Earth-only composites. Aluminium, mineral-fibre composite, and glass are the leading *locally-sourceable* candidates at highland Peary. Titanium is excellent but is NOT locally available here (no ilmenite) — so imported robots may use it, but the "from the Moon" goal points to aluminium/regolith composites for any locally-built robots. The specific selection is an engineering decision.

**Feedstock note (stated as fact, not resolved):** The mineral-fibre composite is referred to elsewhere in this project as "basalt composite," because basalt fibre is the well-characterised terrestrial reference material. The actual Peary feedstock is highland **anorthosite**, not basalt — so the real armour would be an anorthosite/regolith-derived mineral fibre, whose properties differ from terrestrial basalt fibre and are not yet characterised. Both terms describe the same intent (a locally-sourced mineral-fibre composite skin); the reader should read "basalt composite" in the robot documents as feedstock-referenced shorthand. See `systems/sintering/laser-sintering-physics.md` for the basalt-vs-anorthosite distinction and `systems/processing-modules/m-basalt.md` for the fibre-production feedstock question.

2. **No ferromagnetic materials on exterior surfaces** — lunar dust is electrostatically charged and behaves like fine magnetic particles in the presence of ferromagnetic materials. Iron and steel are therefore excluded from all exterior-facing components. Titanium and aluminium are non-magnetic and preferred.

3. **Everything protected when not in use** — every interface, every connector, every sensor is shielded from the lunar environment when not actively engaged. Nothing is left exposed unnecessarily.

---

## Shape and Dimensions (Estimated)

The chassis is a compact, enclosed body — smooth exterior, no protruding elements except the tool head and leg attachment interfaces. All sensitive systems are internal. The shape is approximately elliptical when viewed from above, widest at the midpoint, tapering toward front and rear.

Estimated dimensions:
- Length: 1.2–1.5 m
- Width: 0.8–1.0 m
- Height (body only, excluding head): 0.3–0.4 m

These are starting estimates. Final dimensions depend on the mass budget, leg geometry, and internal component layout — all of which require engineering analysis that does not yet exist.

---

## The Nine Universal Coupling Points

The chassis has **nine identical universal coupling interfaces**:

- **Eight leg coupling points** — distributed symmetrically around the chassis perimeter, four per side
- **(Under review) one front coupling point** — in the detachable-head design, a ninth universal coupling at the **front** (spider position) carries a removable head. In the integrated head-less direction now being evaluated, this point may be dropped in favour of body-integrated sensing. See the "Sensing & Head" section below and `OPEN-DESIGN-INQUIRY-robot-head.md`.

All eight leg interfaces are identical in mechanical design, electrical connection, and optical connection. Any leg can attach to any leg coupling point. **In the detachable-head design**, the front coupling is universal too, so the head is removable just like a leg (swap for repair or harvest from a dead unit) — keeping a nine-identical-interface scheme (8 legs + 1 head). **In the integrated direction**, sensing is built into body and legs and there is no separate head to attach; the brain stays in the body in either case.

This universality is fundamental to the design philosophy:
- Any leg can function as an arm — the AI decides which legs to reassign based on current task and terrain
- A damaged leg is decoupled and discarded — the AI immediately recalculates the optimal configuration for the remaining legs
- A leg stuck in terrain can be deliberately decoupled to free the robot — no mechanical lockup propagates to the rest of the chassis
- Future leg or head types can be introduced without redesigning the chassis

The AI continuously monitors which coupling points are occupied, what type of component is attached, and what configuration is optimal for the current task. When a reconfiguration occurs — planned or due to failure — the AI updates its model within seconds and resumes operation.

**Eight legs plus one head is considered the optimal baseline.** More coupling points would add mass and complexity without proportional benefit. Fewer would reduce redundancy. This number is a founder's recommendation, not a fixed constraint — engineers may reach a different conclusion.

---

## Sensing & "Head" — Active Design Direction (Integrated, Head-less)

> **This section is under active review and we are seeking engineering validation.**
> We are taking the lead with an **integrated, head-less** concept and treating the earlier
> **detachable-head** design as what it may supersede. We are explicitly asking engineers:
> did we make the right call, or should we step back? The full trade-off and the validation
> questions are in **`OPEN-DESIGN-INQUIRY-robot-head.md`** at the repo root.

**The direction we are now taking (head-less, integrated):**

We questioned a basic assumption — *does a machine need a "head" at all, or is that a human/
animal image projected onto a robot?* A spider's head is fused with its body; a self-driving
car has no head, only distributed sensors. So the current direction removes the separate head
and integrates sensing into the **body and legs**:

- **No separate head.** Body + legs as one unit (true to the *8 Legged Freaks* spider form).
  This removes a coupling that can fail, a moving part, a dust-entry point, and a losable
  component.
- **Brain deep in the body.** The strategic compute (Jetson-class) sits in the protected
  three-layer body core — never in an exposed, moving part. *Measuring is not seeing:* the
  robot knows its limb positions from **joint encoders**, judges a sinter/melt from **thermal +
  spectroscopic measurement**, and maps space from **LiDAR/ranging** — none of which needs a
  human-style "eye."
- **Targeted work-sensing between the front legs** — measurement sensors look directly at the
  sinter/melt work zone where the arm-legs operate.
- **360° awareness around the body** — distributed fixed sensors give all-round situational
  coverage; better than any single moving head, which can never see 360° at once.
- **A live camera feed for the human, not the robot.** Every robot must support **override by a
  CMB engineer**, who needs a human-interpretable image. Each robot therefore carries work-zone
  camera(s) **plus** surrounding cameras, so an engineer can assess the whole situation. Given
  the ~2.6 s round-trip delay this is for **situation assessment and re-tasking, not real-time
  control**.

**Open sub-question (deliberately unsolved):** the work-zone sensor faces intense heat, laser
glare, and spatter from the melt — how best to protect it (closable/replaceable window, oblique
off-axis mounting, time-sharing while the laser is hot)? See the inquiry document.

---

### Previous concept (under review) — detachable front head

> The earlier design gave each robot a **detachable head** at the **front** (spider position),
> carrying the sensors and working-laser optics, attached through the **same universal EPM
> coupling as the legs** — so it could be swapped or harvested from a dead unit like a leg, and
> the nine-identical-interface idea (8 legs + 1 head) stayed intact. The brain stayed in the
> body even in that version. We have **not deleted** this concept: it is the fallback if engineers
> judge that an articulated/detachable sensor platform is genuinely needed for precise close-up
> work. The `head-*.md` files describe this earlier model (each carries a superseded banner). The
> validation question — *integrated vs. detachable head* — is open in
> `OPEN-DESIGN-INQUIRY-robot-head.md`.

Note: whichever way this resolves, the **tool head / front coupling point** (if used) shares the
same electromagnetic locking mechanism as all other coupling points (see below), and the brain
remains in the body in both designs.

---

## Coupling Interface — Electromagnetic Lock with Regolith-Composite Protective Cover

Every coupling point — for legs and for the tool head — uses the same interface mechanism:

**Electromagnetic locking:**
The coupling is held by an electromagnet that requires current to release. When current is present and the release command is given, the magnet releases and the component can be decoupled. When current is absent or no release command is given, the component is locked in place. This is a fail-safe design: power loss means the leg or head stays attached, not that it falls off.

**Regolith-composite protective cover:**
Every unused or active coupling point is protected by a small sintered-regolith composite cover plate. When a leg or head is attached, the cover plate moves aside to expose the interface. When the leg or head is removed, the cover plate returns to protect the exposed interface from dust, temperature extremes, and micrometeorite impact.

The cover plate movement is frictionless where possible — the same electromagnetic principle used in the maglev transport system, applied at small scale. The cover requires power only to move, not to stay in position (held by mechanical detent when closed, held by the attached component when open).

This means that at no point is any electrical or optical connector exposed to the lunar environment for longer than the brief moment of coupling or decoupling.

---

## Laser Power Receivers — Distributed Across Entire Body

Rather than a single central laser power receiver that must track the mast BSM, the CMB8LF-L1 uses **distributed receivers across the entire upper chassis surface and potentially the upper leg segments**.

Many small GaAs photovoltaic cells — optimised for the laser wavelength — are distributed across all upper-facing surfaces. Each receiver has a small independent pointing adjustment, driven by voice coil actuators, allowing the AI to optimise the angle of each cell individually for maximum power capture.

**Why distributed receivers:**
- The robot never needs to orient itself toward the mast — it can work in any direction
- If one receiver is dusty, damaged, or shadowed, others continue operating
- The AI selects the optimal active subset at any moment and fine-tunes each cell angle
- Receivers on the upper leg segments extend the total collection area and provide coverage when the chassis is tilted on uneven terrain

The communication laser uses the same receiver network — the same cells that receive power also receive data signals, with the AI distinguishing power and communication wavelengths. This reduces the total number of components required.

All receiver adjustments are small — a few degrees at most. The cells do not track the mast continuously like a solar panel. They are pre-positioned by the AI at the start of each work period and adjusted only when efficiency drops below a threshold.

---

## All-Laser Communication

The CMB8LF-L1 communicates exclusively by laser — no radio systems are used.

**Robot to mast:** Laser link to the nearest BSM on the mast. Power delivery and data communication share the same optical path — different wavelengths, separated by the onboard optics.

**Robot to robot:** Direct laser links between chassis receiver surfaces. Robots working in proximity can communicate directly without routing through the mast.

**Why laser only:**
- The Moon has no atmosphere to scatter or absorb laser signals — zero propagation loss
- No radio frequency interference between robots working in close proximity
- Extremely high data bandwidth at negligible power compared to the sintering laser
- No heavy radio antenna hardware required
- Consistent with the laser-based architecture of the entire system

The mast communicates to Earth via Ka-band radio — laser-to-Earth links are not yet mature enough for operational use at this distance.

---

## Internal Structure

**Structural frame:** Non-ferromagnetic metal alloy — titanium or aluminium, or a combination. The specific alloy is an engineering decision based on mass budget, thermal properties, and manufacturability from lunar resources. No iron-containing alloys on exterior-facing or dust-exposed surfaces.

**Electronics bay:** The central section of the **body** houses the main compute unit (the Jetson-class strategic AI on the prototype), power conditioning electronics, and communication optics — this is the robot's **brain**. It sits inside the body, distinct from the front-mounted head, which carries the senses (the AI does the thinking in the body; the head does the sensing at the front). Thermally coupled to the chassis wall for passive heat management.

**Battery:** Solid-state battery cells distributed through the chassis structure. Total onboard energy storage is intended to provide on the order of a few hours of reduced-power autonomous operation during laser power interruptions — enough to survive shadow periods and communication outages. The exact figure is a concept estimate pending Phase 0 validation; real capacity depends on the final cell choice, robot mass, and how power-hungry the as-built systems turn out to be.

**Exterior:** Sintered regolith composite panels — the same material the robot builds with. Non-magnetic, thermally stable, radiation-resistant, and manufacturable from lunar resources in later phases.

---

## Thermal Management

Peary rim surface temperatures range from approximately −50°C to +10°C — mild compared to equatorial sites but still requiring active thermal management for electronics.

- Multi-layer insulation on all exterior surfaces reduces heat loss during cold periods
- Embedded heaters maintain minimum operating temperatures during shadow periods
- Passive thermal coupling between electronics and chassis wall manages heat during high-power operations
- The regolith-composite exterior acts as a thermal buffer

---

## Mass Estimate

| Configuration | Estimated mass |
|---|---|
| Chassis body only (no legs, no head) | 80–130 kg |
| Full robot with 8 legs, no head | 260–380 kg |
| Full robot with 8 legs and heaviest head | 290–430 kg |

All figures are rough estimates. A real mass budget requires component-level engineering design that does not yet exist. These numbers are starting points for feasibility assessment only.

---

## What Engineers Decide

The following are explicitly left open for engineering expertise:

- Specific alloy composition for structural frame
- Exact number and placement of laser receiver cells
- Detailed coupling interface mechanism design
- Cover plate actuation method (electromagnetic, spring-loaded, or other)
- Exact chassis dimensions and mass budget
- Number of coupling points if 9 proves non-optimal
- Thermal control system specifics

The founder's position: whatever works, works. The constraints are the principles — non-ferromagnetic exteriors, lunar-sourceable materials, universal coupling interfaces, distributed laser receivers, protected connections. How those principles are implemented is engineering.

---

## Open Questions

1. What non-ferromagnetic alloy provides the optimal combination of structural performance, mass, thermal stability, and eventual lunar manufacturability?
2. How many distributed receiver cells are needed for reliable power reception across all expected robot orientations and distances from the mast?
3. What is the minimum cover plate actuation time for the coupling interfaces — and does this create operational delays during head swapping?
4. Can the same optical surface serve both power reception and data communication simultaneously, or does this require optical separation?
5. What is the actual mass of a flight-quality chassis at these specifications?

---

## Power Architecture — Distributed Solid-State Energy Storage

The CMB8LF-L1 uses a fully distributed solid-state battery system. There is no single central battery. Instead, energy storage is distributed across every structural segment of the robot — chassis and all eight legs.

**Why solid-state:**
- No liquid electrolyte — no freezing risk at −150°C, no boiling risk at +130°C
- No leakage or outgassing in vacuum
- Operates across the full lunar surface temperature range without thermal management of the cells themselves
- Mechanically robust — solid-state cells tolerate vibration and impact better than liquid electrolyte cells
- Can be encapsulated completely inside structural components

**Distribution — 25 units total:**

| Location | Units | Primary function |
|---|---|---|
| Foot segment × 8 | 8 | Local sensor power, foot pad force sensing |
| Lower leg segment × 8 | 8 | Knee actuator power, local electronics |
| Upper leg segment × 8 | 8 | Hip actuator power, primary leg energy storage |
| Chassis central | 1 | Main computer, AI, communication optics, head interface |
| **Total** | **25** | Fully distributed across entire robot |

**Why distributed:**

Weight is spread evenly across the entire robot rather than concentrated in one location. This lowers the centre of mass, improves stability on uneven terrain, and means no single point concentrates significant mass.

Redundancy is built in automatically — if a leg segment is damaged and discarded, only the energy stored in that segment is lost. The remaining 24 units continue operating without interruption. The AI adjusts power routing instantly.

Each solid-state unit is sized to contribute a proportional share of the total energy budget. The chassis unit is the largest — it powers the most critical systems. The foot units are the smallest — they power only local sensors.

---

## Hibernation System

During shadow periods — when the Peary rim site loses solar illumination — the laser power system shuts down and the robots enter hibernation. The distributed solid-state energy system sustains the robot through these periods on minimal power draw.

**Hibernation sequence:**
1. Laser power drops below operational threshold
2. AI detects power loss and initiates hibernation protocol
3. All non-essential systems shut down immediately — sintering, locomotion, active sensors
4. Robot halts at current position and locks all leg joints in place
5. Low-power heating activates across all 25 solid-state units and critical electronics — just enough to prevent temperature dropping below minimum operating threshold
6. AI enters minimal monitoring mode — checking power levels and temperature only
7. Communication laser remains active at minimal power for contact with mast

**On power restoration:**
1. Solar curtain generates first power as illumination returns
2. Mast detects power and sends wake signal via communication laser
3. AI exits hibernation — systems initialise sequentially
4. Temperature check across all segments before locomotion resumes
5. Robot resumes task from exact position where it halted

The hibernation heating draw is a small fraction of operational power — the distributed solid-state units across 25 locations provide enough reserve for the longest expected shadow periods at Peary, estimated at a few days based on published illumination data.

---

## Full Layer Architecture — "Everything Inside the Bone"

Every structural segment of the CMB8LF-L1 — all eight leg segments (foot, lower leg, upper leg) and the chassis body — follows identical layered construction from inside out:

**Layer 1 — The Bone (structural core):**
Non-ferromagnetic structural alloy — titanium, aluminium, or combination. Hollow tube or shell. Houses all electronics, solid-state battery cell, actuator controller, heater, and sensors for that segment. Everything electronic lives inside the structural material, protected from the outside by the structure itself.

**Layer 2 — The Gel (protective surround):**
Thermally conductive, mechanically damping gel completely surrounding the bone. Absorbs shock and vibration. Conducts heat from electronics to the outer shell for passive radiation. Must remain stable across the full lunar temperature range in vacuum — specific formulation is an open engineering question.

**Layer 3 — The Armour (sintered-regolith composite exterior):**
Sintered regolith composite outer shell. Non-magnetic. Thermally stable. Radiation resistant. Manufacturable from lunar resources in later phases. This is the surface that contacts the lunar environment — dust, temperature extremes, micrometeorite flux, radiation.

**The principle:** nothing electronic or sensitive is ever exposed to the lunar environment. The bone protects the electronics. The gel protects the bone. The regolith composite protects the gel. Three layers between the electronics and the Moon.

**Frictionless where possible:**
All moving interfaces — leg joints, cover plates, coupling mechanisms — use electromagnetic principles to eliminate or minimise mechanical friction. No lubricants that could fail in vacuum or temperature extremes. No mechanical wear surfaces exposed to lunar dust. Where friction cannot be avoided, dry film coatings rated for vacuum and the full temperature range are used.

---

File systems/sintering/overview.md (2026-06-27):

# Sintering — Overview
## Chrystal Moon Base — Core Construction Process

**Status:** Based on published research — not yet demonstrated at required scale  
**Licence:** CC0

---

## What Sintering Is

Sintering is the process of fusing loose granular material into a solid mass by applying heat below the material's full melting point. At sufficient temperature, the grains bond at their contact points without liquefying — producing a solid, porous material. At higher temperatures approaching the melting point, the bonds become denser and the material approaches a glass-ceramic solid.

For CMB's purposes, the target is dense, crack-free sintered regolith (highland anorthosite) — strong enough to serve as a structural floor for dome foundations, robot operations, and eventually human habitation.

---

## Why Sintering, Not Casting

- **Lower energy requirement** — sintering requires less energy per unit volume than full melting and casting
- **No mould required** — sintered material is built up layer by layer in place
- **In-situ capability** — the laser system can sinter directly on the surface without transporting material
- **Scalability** — the sintering area can expand continuously as the robot works

---

## Published Research Basis

- Fateri et al. (2019) — *Solar Sintering for Lunar Additive Manufacturing*, J. Aerospace Eng. 32(6) — solar-sintered simulant samples. https://doi.org/10.1061/(ASCE)AS.1943-5525.0001093
- Taylor et al. — laser sintering with CO₂ laser at various energy densities
- Meurisse et al. (2018) — *Solar 3D printing of lunar regolith*, Acta Astronautica 152, 800–810 — solar 3D printing of lunar simulant patches. https://doi.org/10.1016/j.actaastro.2018.06.063

The challenge is scaling these results to construction-relevant areas (square metres to hectares) while maintaining consistent quality.

---

## Document Index

| Document | Description |
|---|---|
| laser-sintering-physics.md | Physical principles of laser sintering |
| crack-prevention.md | Strategies to prevent thermal cracking |
| energy-budget-per-m2.md | Energy required per square metre |

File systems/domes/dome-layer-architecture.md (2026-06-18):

# Dome Layer Architecture
## Chrystal Moon Base — Habitat System Concept

**Status:** Concept proposal  
**Licence:** CC0

---

## Overview

Every dome on the Chrystal Moon Base is a multi-layered composite structure. The layered approach is not an engineering luxury — it is a survival requirement. Each layer addresses a specific threat: radiation, micrometeorite impact, thermal extremes, pressure loss, and long-term material degradation. No single material can address all of these threats simultaneously. Multiple layers, each optimised for its specific role, provide the combined protection required for long-duration human habitation on the lunar surface.

The target dome count for a fully operational Phase 2 base is approximately 90–100 domes of varying sizes and functions. All domes share the same layer architecture. Differences between dome types are in size, internal configuration, and secondary support structures — not in the protective layer design.

> **⚠ Unresolved contradiction — transparency vs radiation shielding (flagged for decision).**
> Several dome documents describe residents *looking up through the dome at the
> stars, the sun, and Earth*. But Layer 1 below is a **2–5 m opaque sintered-regolith
> radiation shell**. A dome cannot be both metres-thick-opaque (shielded) and
> transparent (stargazing) at the same time. These are mutually exclusive. The
> agreed direction (see project decision, June 2026) is: **permanent living is
> underground; the glass/transparent domes are dose-budgeted DAY-USE spaces for
> work and recreation**, not radiation-safe permanent habitats. Each dome type must
> therefore be classified as **either** a shielded (opaque, regolith-shelled) dome
> **or** a transparent (thin, limited-exposure) dome — this classification is a
> design decision still to be made per dome type. Until then, treat any "transparent
> + fully shielded" dome description as internally inconsistent.

---

## The Five-Layer System

Layers are listed from outside to inside — from the lunar environment toward the interior living space.

---

### Layer 1 — Sintered Regolith Shell (Highland Anorthosite)

**Material:** Sintered highland anorthosite regolith  
**Thickness:** TBD by structural engineering  
**Function:** Primary structure, radiation shielding, micrometeorite protection

The outermost layer is sintered directly from the lunar regolith by CMB8LF-L1 robots. It is not a manufactured component delivered from Earth — it is grown in place from the Moon's own material.

The sintered highland-anorthosite shell provides:
- **Mass shielding against radiation** — the primary defence against galactic cosmic rays and solar energetic particles. The required thickness to achieve Mars-equivalent radiation levels inside is a function of sintered-regolith density and composition — this requires calculation with actual Peary regolith composition data, which is not yet available. Estimates suggest 2–5 metres of regolith equivalent for adequate shielding, though thinner layers combined with the water layer (Layer 4) provide substantial additional protection.
- **Micrometeorite protection** — the impact flux at the lunar surface is well characterised. The sintered shell must be thick enough that the largest expected impact within the dome's operational lifetime does not penetrate to Layer 2.
- **Structural load bearing** — the dome geometry distributes compressive loads efficiently. Sintered regolith (glass-ceramic) in compression is strong. The dome must also withstand internal pressure from the habitat atmosphere pressing outward.

**Critical design constraint:** All connections — power, data, water, air — pass through the floor, never through the dome wall or the shell. The shell has no penetrations. This is non-negotiable. Every penetration is a potential failure point. A dome with zero wall penetrations is structurally stronger and more reliable than one with cable entries, pipe fittings, or windows.

The dome is printed by robots using a moulding and sintering process. Molten glass (from Layer 3 printing, which happens simultaneously from inside) is not yet involved at this stage — the regolith shell is printed first as the structural form, then the inner layers are added.

---

### Layer 2 — Self-Sealing Gel

**Material:** Autonomic sealant — specific formulation is an open engineering question  
**Thickness:** TBD  
**Function:** Automatic sealing of micrometeorite penetrations

If a micrometeorite penetrates Layer 1, it may create a small hole that begins leaking the habitat atmosphere. Layer 2 is designed to seal such a hole automatically, without human intervention and without requiring depressurisation of the dome.

The concept is based on self-healing materials research — materials that contain a sealant in a dormant form and activate it on damage. Two approaches exist in current research:

**Microencapsulated sealant:** Tiny capsules distributed throughout the layer rupture when a projectile passes through. The released sealant flows into the breach and cures, sealing the hole. This approach is used in self-healing fuel tanks in military aircraft and has been researched for spacecraft hull applications by NASA and ESA.

**Interpenetrating polymer network:** A two-component system where components are kept separate until a crack or hole brings them into contact, triggering a chemical reaction that forms a solid seal. This approach has been demonstrated in laboratory settings.

**Honest assessment:** Neither approach has been demonstrated at the scale, temperature range, and vacuum conditions required for a lunar dome application. This layer is the most speculative element of the dome architecture. It is included because the concept is scientifically plausible and because the engineering questions it raises are specific and answerable through ground research. If no viable self-sealing material can be validated before dome construction begins, this layer may need to be replaced with an alternative approach — for example, a second sintered regolith layer or a Kevlar-based ballistic barrier.

This is flagged as a priority research question. Contributions from materials scientists are specifically invited.

---

### Layer 3 — Gold-Coated Glass

**Material:** High-purity glass with high-temperature reinforcing fibre (material TBD — see below) and exterior gold coating  
**Thickness:** TBD  
**Function:** Thermal/optical control (infrared and partial UV reflection), primary transparent barrier

This layer performs three functions simultaneously:

**Gold coating (exterior surface):** A thin-film gold coating on the outer glass surface reflects infrared and a portion of ultraviolet radiation — the same principle as the gold visor on astronaut helmets. Gold is chemically stable in vacuum, does not degrade under radiation, and has been used in spacecraft thermal control for decades. The coating is thin enough to remain partially transparent to visible light while significantly reducing the solar (thermal/UV) load on the interior.

**Important — what gold does NOT do:** The gold coating is a thermal and optical measure, not an ionising-radiation shield. Against galactic cosmic rays (high-energy charged particles), thin high-Z layers like gold provide no meaningful protection and can even generate secondary particles. GCR shielding is the job of the passive mass (regolith shell + water layer) and the underground/sleep zones — see `systems/life-support/radiation-protection.md`. Listing gold here under thermal/optical control keeps that distinction honest.

**Glass structure:** High-purity glass, manufactured from lunar silicon by the M-Glass processing module. The glass is printed in its molten state, inside-out, for maximum homogeneity and minimum defects. This printing method — starting from the inner surface and building outward — ensures that the optical quality of the interior face (which residents will look through) is the highest quality.

**Reinforcing fibre (open materials question — was specified as titanium):**
As the glass is printed in its molten state, robots lay continuous reinforcing
fibre into the melt. The composite — fibre-reinforced glass — is much stronger in
tension than plain glass, which is critical for a pressure vessel where the
interior atmosphere pushes outward. **Material choice is unresolved and must
satisfy two constraints at once: survive the glass melt temperature, and be
sourceable at highland Peary.** Titanium (earlier baseline) survives the melt but
is **not locally available** at Peary (no ilmenite). Aluminium *metal* fibre is
locally abundant but **melts at ~660 °C — far below glass working temperature — so
it cannot be laid into molten glass.** The realistic candidates are therefore
**high-temperature, locally-sourceable fibres**: alumina (Al₂O₃) ceramic fibre
(Peary regolith is ~27% Al₂O₃) or anorthosite/mineral fibre (the M-Mineral-Fibre
line). Both melt-compatible and local; both have lower tensile strength than
titanium and are **not yet characterised** for this use. This is flagged for
materials-engineering input, not asserted.

---

### Layer 4 — Water

**Material:** Liquid water  
**Thickness:** TBD — engineering trade between radiation protection and structural load  
**Function:** Temperature regulation, radiation moderation

A layer of liquid water between the two glass layers serves two distinct purposes:

**Radiation moderation:** Water is an excellent moderator of neutron radiation and provides meaningful shielding against other particle radiation types. The hydrogen atoms in water are particularly effective at slowing and absorbing neutrons produced by cosmic ray interactions with the dome structure. A water layer of sufficient thickness makes a measurable contribution to reducing the radiation dose inside the dome.

**Temperature regulation:** The thermal mass of water buffers temperature fluctuations inside the dome. During the lunar day, the dome exterior heats; the water absorbs this heat slowly. During the lunar night (or during the brief illumination gaps at Peary), the water releases stored heat, moderating the interior temperature drop. This passive thermal regulation reduces the load on the dome's active heating and cooling systems.

**Water source:** All water for the dome layers comes from lunar sources — extracted from regolith processing and from nearby cold trap ice deposits. Water is accumulated over years of robotic operations before the first dome is pressurised. It is stored in underground sintered cisterns. No dome water needs to be imported from Earth.

**Freeze risk:** At Peary rim temperatures, water in a sealed layer could freeze during illumination gaps. The thermal design must ensure the water layer remains liquid under all expected operating conditions, or that freezing can be tolerated without structural damage. This is a specific engineering challenge that requires analysis.

---
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

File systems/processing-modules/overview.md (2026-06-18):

# Processing Modules — Overview & Index

**Status:** Index to the factory landscape. All modules are concept proposals with
sourced grounding; tentative throughout. **Ground truth: Peary is highland / anorthosite**
(`../../PEARY-MATERIALS-REFERENCE.md`).
**Licence:** CC0

> Visual map: **`processing-chain-diagram.svg`** (renders in GitHub).
> Chain & ordering logic: **`../../roadmap/processing-chain-peary.md`**.
> Growth/gates: **`../../roadmap/growth-model-gated.md`**.

---

## The chain in one line

Energy → **build line** (raw → structure) → **MRE keystone** (raw O₂ + metals + slag) →
**purification** (per substance) → **near-closed recycling** → store → humans last.

Design rule across all modules: *no shortcuts; minimise Earth dependence.* Each module
states what is local and what (if anything) must be imported.

---

## Stage 1 — Build line (comes first)

| Module | Makes | Earth-dependence |
|---|---|---|
| [`m-build-sintering`](m-build-sintering.md) | floors, walls, halls, silos (sintered/melted regolith) | none |
| [`m-cement`](m-cement.md) | geopolymer binder (low-energy, castable) | alkali activator (NaOH) |

## Stage 2 — Keystone

| Module | Makes | Earth-dependence |
|---|---|---|
| [`m-mre-electrolysis`](m-mre-electrolysis.md) | oxygen + mixed metal alloys + ceramic slag | none |
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

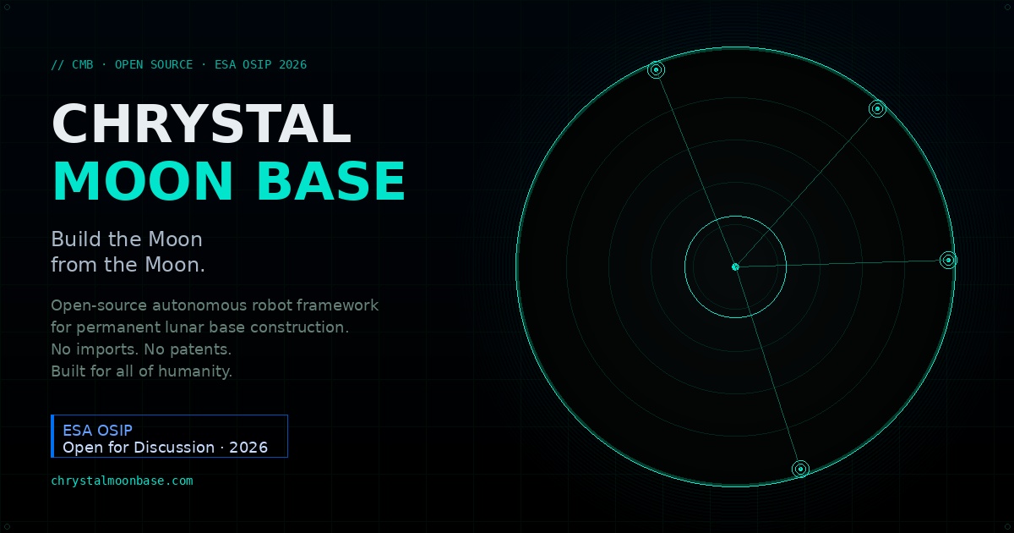
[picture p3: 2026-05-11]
public/assets/images/og-image.jpg

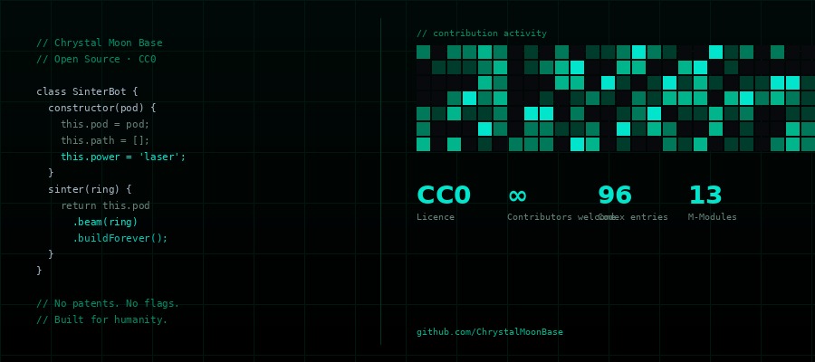
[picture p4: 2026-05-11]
public/assets/images/github-visual.jpg

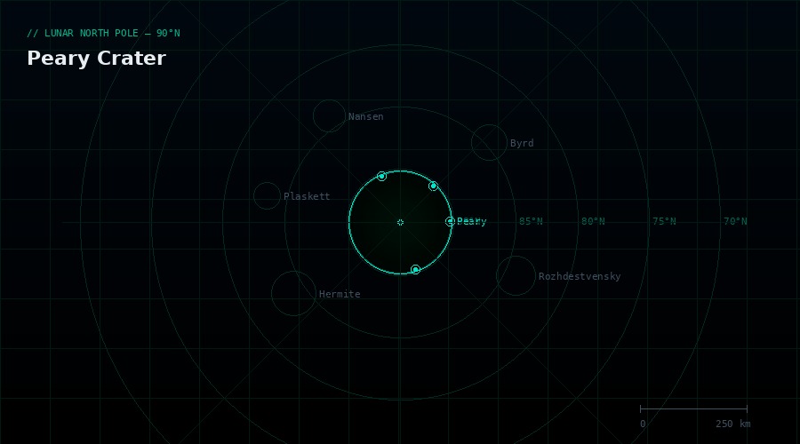
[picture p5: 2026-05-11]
public/assets/images/lunar-north-pole.jpg

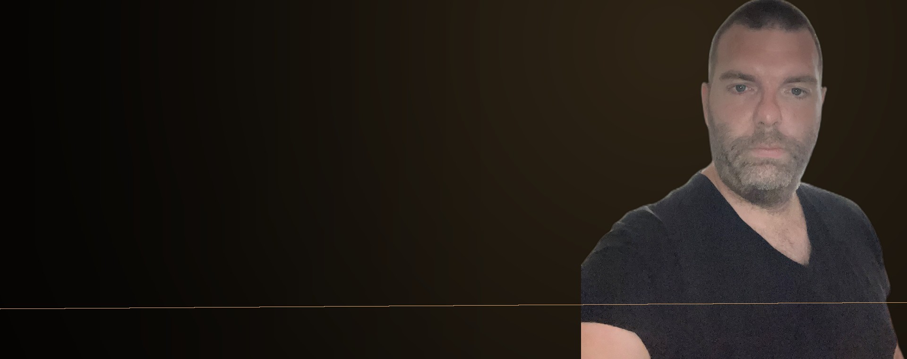
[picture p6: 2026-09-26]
public/assets/images/berechja.jpg

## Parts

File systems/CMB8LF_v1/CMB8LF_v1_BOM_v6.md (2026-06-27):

# CMB8LF-S1 — Bill of Materials v6
## Chrystal Moon Base · 8 Legged Freaks · Volledige Revisie
**Brushless · 24V Gedistribueerd · CAN Bus · Vacuum-Proof**
**CC0 · Berechja Kerkdijk · 2026**

---

## Wat v6 verandert ten opzichte van v5

| Verandering | Reden |
|---|---|
| Alle hobby servos → brushless BLDC + moteus | Precisie · koppelregeling · 24V native |
| PCA9685 → CAN bus (USB-CAN adapter) | Één bus voor alle 26 motoren |
| Centrale batterij → 25 gedistribueerde nodes | Fault tolerant · gewicht verdeling |
| PC Space Grade → PEEK-CF | Hogere temperatuur · vacuum betere outgassing |
| Laser 650nm symbolisch → 808nm/976nm echt | Echt glaspoeder smelten |
| Tripod gait → Wave gait | Maximale stabiliteit |
| Standaard lagers → Si₃N₄ keramisch | Vacuum-proof · smeervrij |

---

## KOSTENSTRUCTUUR PER MODULE

```
MODULE               KOSTEN      PRIORITEIT
─────────────────────────────────────────────
1 standaard been     ~€365       Eerst bouwen
1 grijper been       ~€520       Tweede been
Hoofd                ~€310       Derde
Body + compute       ~€640       Laatste (incl. Jetson)
Printer (éénmalig)   ~€700-4500  Zie sectie 10
─────────────────────────────────────────────
INDICATIE per bouwblok — zie BUDGET TOTAALOVERZICHT
onderaan voor de volledige optelling (~€6.815 excl. printer).
Per maand (1 been)   ~€365-520
```

> **Let op:** dit blokje is een *indicatieve* kostenstructuur per bouwblok (handig voor
> "wat kost de volgende stap"). Het is bewust grof en telt **niet** op tot het robot­totaal —
> de volledige, post-voor-post optelling staat in **BUDGET TOTAALOVERZICHT** onderaan
> (~€6.815 robot, ~€7.497 incl. 10% buffer, excl. printer).

---

## 1. COMPUTE & AI — €453

| Onderdeel | Aantal | Prijs/st | Totaal | Functie |
|---|---|---|---|---|
| NVIDIA Jetson Orin Nano Super 8GB | 1 | €249 | €249 | Hoofd AI · navigatie (67 TOPS, 7–25 W) |
| Raspberry Pi Pico W | 2 | €10 | €20 | CAN master · safety |
| RP2350 module | 26 | €4 | €104 | Mini AI per segment + hoofd |
| NVMe M.2 SSD 256GB | 1 | €20 | €20 | Jetson opslag (boot) |
| USB-CAN adapter (Canable) | 1 | €25 | €25 | Jetson → CAN bus |
| USB hub 4-poort | 1 | €15 | €15 | USB devices Jetson |
| Kleine breadboard PCB's | 10 | €2 | €20 | Verbindingen compute bay |
| **Subtotaal** | | | **€453** | |

> **Waarom Jetson i.p.v. Raspberry Pi 5 (gewijzigd):** het hoofdbrein draait de zware AI
> (visie, SLAM, gait-planning, real-time sensorfusie). De Jetson Orin Nano Super levert
> ~67 TOPS GPU-versnelde inferentie — ordes meer dan de Pi 5 — wat nodig is voor de
> spectroscopie-/visie-pipeline en on-board modellen. De gelaagde architectuur blijft
> ongewijzigd: **Jetson** (strategisch brein) · **Pico W ×2** (CAN-master + safety) ·
> **RP2350 ×26** (per-segment reflexen). Alleen de bovenste laag is vervangen; de CAN-bus,
> moteus-controllers en per-segment-AI blijven exact gelijk. Stroom (7–25 W) wordt geleverd
> door de bestaande Buck 5V/10A rail. Voor het prototype wordt **één** Jetson aangeschaft.

---

## 2. MOTOREN & CONTROLLERS — €2.180

### 2A. moteus r4.11 CAN Controllers

| Onderdeel | Aantal | Prijs/st | Totaal | Noot |
|---|---|---|---|---|
| mjbots moteus r4.11 | 26 | €85 | €2.210 | 24 been + 2 hoofd |

> **BOUWTIP**: Bestel moteus controllers gefaseerd — 3 per been × 8 benen.
> Eerste bestelling: 3 stuks voor been 1. Zo spreidt je de kosten.

### 2B. BLDC Motoren

| Onderdeel | Aantal | Prijs/st | Totaal | Positie |
|---|---|---|---|---|
| iPower GM5208-150T | 8 | €28 | €224 | Heup (coxa) — hoogste koppel |
| iPower GM4108H-120T | 10 | €22 | €220 | Knie (femur) + hoofd pan |
| iPower GM3506-2 | 8 | €18 | €144 | Enkel (tibia) + hoofd tilt |
| **Subtotaal motoren** | | | **€588** | |

### 2C. Encoder (ingebouwd in moteus — geen extra nodig)
*De moteus r4.11 heeft AS5047P encoder interface ingebouwd.*
*Encoders zijn inbegrepen in de moteus prijs.*

### 2D. Grijper Vinger Servos (klein — brushless te groot)

| Onderdeel | Aantal | Prijs/st | Totaal | Noot |
|---|---|---|---|---|
| MG90S mini servo | 8 | €4 | €32 | 4 vingers × 2 grijper benen |
| Servo driver PCA9685 | 2 | €6 | €12 | 1 per grijper been |
| **Subtotaal grijpers** | | | **€44** | |

---

## 3. BATTERIJEN & POWER — €480

### 3A. Segment Batterijen (25 nodes)

> **Waarom 25 nodes?** Ontwerpprincipe: **elk bewegend segment heeft zijn eigen kleine
> batterij** in plaats van één centrale accu. Valt één node uit, dan verliest de robot
> alleen dat segment — de rest blijft werken (fault-tolerance + gewichtsverdeling). Het
> getal volgt uit de segment-telling (~8 poten met hun been-segmenten + body), niet uit
> het aantal poten. **25 is een schaalbare werkwaarde**: het definitieve aantal hangt af
> van het uiteindelijke aantal onafhankelijke segmenten en wordt door engineering/
> professionals bepaald. Het principe (één node per segment) staat vast; het exacte
> aantal niet.

| Onderdeel | Aantal | Prijs/st | Totaal | Noot |
|---|---|---|---|---|
| 16340 Li-Ion 700mAh (losse cel) | 150 | €2.50 | €375 | 6 per segment × 25 |
| 6S mini BMS 5A | 24 | €6 | €144 | 1 per been-segment |
| Nikkelstrip 0.15mm × 8mm | 5m | €8 | €40 | Celverbindingen |
| **Subtotaal segment power** | | | **€559** | |

### 3B. Body Batterij

| Onderdeel | Aantal | Prijs/st | Totaal | Noot |
|---|---|---|---|---|
| LiPo 4S 5000mAh XT60 | 1 | €45 | €45 | Body electronics |
| 4S 30A BMS | 1 | €10 | €10 | Body batterij |
| Buck 5V/10A | 2 | €10 | €20 | Jetson + Pico W power |
| Buck 3.3V/3A | 6 | €5 | €30 | RP2350 per segment |
| E-stop knop NC 22mm rood | 1 | €5 | €5 | Hardware noodstop |
| Relaismodule 30A | 1 | €8 | €8 | E-stop schakeling |
| XT60 connectoren | 20 | €0.80 | €16 | Power verbindingen |
| Anti-spark XT60 | 2 | €4 | €8 | Veilig aansluiten |
| Lader 4S balanceer (ISDT Q6) | 1 | €45 | €45 | Body lader |
| Lader 6S balanceer | 1 | €55 | €55 | Segment lader |
| **Subtotaal body power** | | | **€242** | |

---

## 4. CAN BUS & BEDRADING — €95

| Onderdeel | Aantal | Prijs/st | Totaal | Noot |
|---|---|---|---|---|
| Twisted pair CAN kabel 26AWG | 20m | €3/m | €60 | H+L door alle botten |
| 120Ω CAN terminatieweerstand | 20 | €0.30 | €6 | 2 per CAN lijn |
| JST-GH 4-pin (CAN + power door koppeling) | 30 | €1 | €30 | Per koppelingsinterface |
| Kabelgoten PEEK-CF snap | geprint | — | — | Ontwerp in CAD |
| **Subtotaal CAN** | | | **€96** | |

---

## 5. KOPPELINGSSYSTEEM — €320

### Bistabiele Magneetkoppeling × 9 (8 benen + hoofd)

| Onderdeel | Aantal | Prijs/st | Totaal | Noot |
|---|---|---|---|---|
| NdFeB N52 magneetring ⌀40mm | 9 | €12 | €108 | Permanente vergrendeling |
| Release spoel (custom wikkeling) | 9 | €8 | €72 | 50ms puls ontgrendeling |
| Si₃N₄ keramisch kogellager ⌀30mm | 18 | €15 | €270 | 2 per koppeling |
| Vergoud pogo pin set 5-pins | 9 | €8 | €72 | Power + CAN contact |
| Hall sensor A3144 | 9 | €1 | €9 | Vergrendeld/los detectie |
| PEEK-CF geleidingsneus (geprint) | 9 | — | — | CAD ontwerp |
| MoS₂ dry film spray 400ml | 2 | €25 | €50 | ALLE bewegende vlakken |
| **Subtotaal koppeling** | | | **€581** | |

---

## 6. SENSOREN — €375

| Onderdeel | Aantal | Prijs/st | Totaal | Bus | Positie |
|---|---|---|---|---|---|
| RPLIDAR A1M8 | 1 | €90 | €90 | UART → Jetson | Hoofd |
| Pi Camera 3 NoIR | 1 | €28 | €28 | CSI → Jetson | Hoofd |
| FLIR Lepton 3.5 | 1 | €180 | €180 | SPI → Jetson | Hoofd |
| BNO055 IMU | 1 | €8 | €8 | I2C → Jetson | Hoofd |
| VL53L1X ToF | 2 | €5 | €10 | I2C → Jetson | Hoofd links+rechts |
| MLX90614ESF | 2 | €8 | €16 | I2C → RP2350 | Palm ×2 |
| TMP117 precisie temp | 26 | €4 | €104 | I2C → RP2350 | Per segment |
| INA226 stroom monitor | 10 | €4 | €40 | I2C → Pico W | Power rails |
| **Subtotaal sensoren** | | | **€476** | | |

---

## 7. LASER PALM SYSTEEM — €180 (×2 palmen)

| Onderdeel | Aantal | Prijs/st | Totaal | Noot |
|---|---|---|---|---|
| Laserdiode 808nm 2W TO-56 | 2 | €35 | €70 | L1 sinter (1 per palm) |
| Laserdiode 976nm 1W TO-56 | 2 | €25 | €50 | L2 anneal (1 per palm) |
| Asferische collimeer lens 4.51mm EFL | 2 | €18 | €36 | L1 focus |
| Defocus barrel optiek | 2 | €12 | €24 | L2 brede spot |
| Messing lensbarrel M5 | 4 | €6 | €24 | Houder per lens |
| CC laser driver switching 2A | 2 | €15 | €30 | L1 driver |
| CC laser driver PWM 1A | 2 | €12 | €24 | L2 driver |
| AL6061 palmkern 65×50×40mm | 2 | €25 | €50 | CNC of printservice |
| OD4+ laserbril 808+976nm | 1 | €45 | €45 | VERPLICHT · gedeeld |
| **Subtotaal laser** | | | **€353** | |

---

## 8. MECHANISCH — €175

| Onderdeel | Prijs | Noot |
|---|---|---|
| M3 RVS bouten assortiment 300 stuks | €14 | Alle assemblages |
| M2 RVS bouten assortiment 150 stuks | €9 | Kleine componenten |
| M3 messing heat-set 100 stuks | €8 | PEEK-CF verbindingen |
| M2 messing heat-set 60 stuks | €6 | Kleine prints |
| M3 nyloc moeren 100 stuks | €6 | Vibratie-vast |
| Si₃N₄ keramische lagers F688 ×40 | €80 | Heup + knie gewrichten |
| Titaan M3 bouten 50 stuks | €25 | Exterieur (non-magnetisch) |
| Krimptube assortiment | €8 | Alle verbindingen |
| Isopropanol 99% 500ml | €10 | Reiniging voor assemblage |
| Thermische pasta vacuüm-grade | €12 | Motor → structuur |
| **Subtotaal** | **€178** | |

---

## 9. THERMISCH & VACUUM COATING — €145

| Onderdeel | Prijs | ASTM E595 | Noot |
|---|---|---|---|
| Bergquist GAP PAD HC5.0 200×200mm | €60 | TML 0.05% ✅ | Motor → kern |
| Silica aerogel blanket 300×300×6mm | €40 | ✅ | Thermische isolatie |
| Aeroglaze Z306 mat zwart spuitbus | €50 | ✅ | Buitencoating |
| MasterSil 323AO-LO 50g | €40 | ✅ | Vacuum adhesief |
| **Subtotaal** | **€190** | | |

---

## 10. VERLICHTING — €65

| Onderdeel | Aantal | Prijs | Totaal |
|---|---|---|---|
| WS2812B LED strip 60LED/m | 2m | €12 | €24 |
| 850nm IR LED 1W | 6 | €4 | €24 |
| 10W LED spotlight module | 1 | €8 | €8 |
| IR LED driver MOSFET | 3 | €3 | €9 |
| **Subtotaal** | | | **€65** | |

---

## 11. GEREEDSCHAP (éénmalig) — €185

| Onderdeel | Prijs |
|---|---|
| Soldeerbout 65W temperatuurgeregeld | €50 |
| Fijn soldeertin 60/40 0.6mm | €10 |
| Digitale schuifmaat 0.01mm | €20 |
| Heat-set tool M2+M3 | €12 |
| Multimeter Fluke of gelijkwaardig | €30 |
| Oscilloscoop USB 50MHz | €35 |
| Precisie schroevendraaier set | €15 |
| Anti-statische mat + armband | €13 |
| **Subtotaal** | **€185** | |

---

## 12. FILAMENT — €485

| Materiaal | Hoeveelheid | Prijs | Gebruik | Vacuum |
|---|---|---|---|---|
| PEEK-CF (Kimya of 3DXTech) | 8 × 500g | €55/rol | Alles structureel | ✅ TML <0.1% |
| PA12-CF | 2 × 500g | €45/rol | Koppelings-neus · glijdende vlakken | ✅ |
| PEEK naturel (testprint) | 1 × 500g | €55 | Maatcontrole vóór CF print | ✅ |
| **Subtotaal** | | **€595** | | |

---

## 13. 3D PRINTER

### PRIMARY (selected) — CreatBot PEEK-300 (~€14.999)
**CreatBot PEEK-300** — dedicated high-temperature PEEK printer
- Prints PEEK-CF directly (high stable chamber temperature, high-temp hotend, reliable thermal control)
- **Built-in annealing — no separate oven needed.** The heated chamber holds the part at temperature during and after printing (in-situ annealing). PEEK must cool slowly and be held at temperature for correct crystallinity (strength, dimensional stability) — normally a separate oven step. Building it in removes that step: less equipment, less handling, no distortion from moving the part. (Most demanding crystallinity may still use a longer dedicated anneal; for the prototype and most Nexus Ignis parts the built-in annealing suffices.)
- Purpose-built for PEEK — not a marginal/budget machine pushed to its limits
- **Dual-purpose rationale:** this is also the Nexus Ignis B.V. production printer. The same investment serves two functions — it generates revenue as the Nexus Ignis PEEK/polymer printing service, *and* it prints the CMB8LF prototype robot. The commercial entity's machine is what physically makes the open-source robot possible. One investment, two purposes.

**Why not a cheaper printer:** budget machines can technically attempt PEEK-CF, but it is not wise — PEEK-CF demands high stable chamber temperatures, a true high-temp hotend, and reliable thermal control. A failed PEEK print on a borderline machine costs more in time and material than the reliability of a machine built for it. Quality and commercial use coincide here, so the dedicated printer is the sensible choice rather than the cheapest.

---

**DIY ALTERNATIVES (for open-source contributors without a CreatBot):**

### Alt 1 — Intamsys FUNMAT HT Enhanced (€3.500-4.500)
- Real PEEK printer; chamber to 90°C; nozzle 450°C; ready out of the box

### Alt 2 — Voron 2.4 self-build + Phaetus Rapido HF 2 UHF (€1.800-2.500)
- Self-build (3-4 weekends); with chamber heater mod 80-100°C; can print PEEK after calibration; large community support

### Alt 3 — Budget non-PEEK (€699, e.g. QIDI Q1 Pro / Bambu P1S)
- Cannot print PEEK-CF; only PA12-CF / PC-CF
- Use a print service for PEEK parts (e.g. Xometry €20-60 per part)
- Only suitable for a non-PEEK prototype start, not the final vacuum-rated build

---

## BUDGET TOTAALOVERZICHT

| Module | Kosten |
|---|---|
| Compute & AI | €453 |
| Motoren + controllers | €2.842 |
| Batterijen + power | €801 |
| CAN bus + bedrading | €96 |
| Koppelingssysteem | €581 |
| Sensoren | €476 |
| Laser palm systeem | €353 |
| Mechanisch | €178 |
| Thermisch + coating | €190 |
| Verlichting | €65 |
| Gereedschap (éénmalig) | €185 |
| Filament | €595 |
| **ROBOT TOTAAL** | **~€6.815** |
| Buffer 10% | €682 |
| **EINDTOTAAL excl. printer** | **~€7.497** |

---

## BOUW-PER-BEEN STRATEGIE

```
MAAND 1       Gereedschap + printer
              Compute (Jetson + Pico W + RP2350)
              CAN adapter + test setup
              Kosten: ~€500-1.000

MAAND 2       Eerste standaard been
              3× moteus + motoren + batterij
              PEEK-CF filament (of printservice)
              Test: CAN node actief
              Kosten: ~€365

MAAND 3       Eerste grijper been
              Laser palm systeem
              OD4+ laserbril (verplicht)
              Kosten: ~€520

MAAND 4-8     Overige 6 benen
              ~€365 per standaard been

MAAND 9       Hoofd + sensoren
              FLIR Lepton + LIDAR + camera's
              Kosten: ~€470

MAAND 10      Body + koppelingen
              Bistabiele magneten + pogo pins
              Kosten: ~€600

MAAND 11-12   Kalibratie + software
              Wave gait tuning
              Laser sinter test
              Eerste demo
```

---

## VACUÜM GEREEDHEID CHECKLIST

| Component | Aarde demo | Vacuüm test | Fix |
|---|---|---|---|
| PEEK-CF | ✅ | ✅ TML <0.1% | — |
| PA12-CF | ✅ | ✅ | — |
| Si₃N₄ lagers | ✅ | ✅ | — |
| MoS₂ coating | ✅ | ✅ | — |
| Moteus r4.11 | ✅ | ⚠️ | Aeroglaze coating op PCB |
| 16340 Li-Ion | ✅ | ⚠️ | Seal in PEEK behuizing |
| Silicoon kabel | ✅ | ✅ | — |
| NdFeB magneten | ✅ | ✅ | — |
| Bergquist pads | ✅ | ✅ | — |
| Aeroglaze Z306 | ✅ | ✅ | — |
| MasterSil 323AO-LO | ✅ | ✅ | — |
| MG90S servo (vingers) | ✅ | ⚠️ | Vervangen door mini brushless voor vluchtversie |

---

*CMB8LF-S1 · BOM v6 · Volledige Revisie*
*Multi-AI: Claude · ChatGPT · Gemini · DeepSeek · Meta*
*Human decisions: Berechja Kerkdijk*
*CC0 2026 — Chrystal Moon Base — No rights reserved*
*No flags. No patents. For all humanity. 🌙*

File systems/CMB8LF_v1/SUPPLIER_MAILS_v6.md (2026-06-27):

# CMB8LF-S1 — Supplier Contact Templates v6
## Bestelmails voor alle kritieke componenten
**CC0 · Chrystal Moon Base · 2026**

---

## mjbots — moteus r4.11 Controllers

**Website:** mjbots.com
**Product:** moteus r4.11

```
Subject: Order inquiry — moteus r4.11 (quantity 26)

Hello,

I am building an 8-legged robotics prototype for a lunar ISRU
demonstration project (Chrystal Moon Base, ESA OSIP qualified).

I would like to order 26x moteus r4.11 controllers.
Please confirm availability, lead time, and shipping to Netherlands.

Thank you,
Berechja Kerkdijk
info@chrystalmoonbase.com
```

---

## iPower Motor — BLDC Motors

**Website:** ipower-motor.com
**Products:** GM5208-150T (×8) · GM4108H-120T (×9) · GM3506-2 (×9)

```
Subject: Bulk order — BLDC motors for robotics prototype

Hello iPower Motor,

I am building an 8-legged robot prototype for a lunar robotics
research project. I need the following motors:

- GM5208-150T: 8 units (hip joints)
- GM4108H-120T: 9 units (knee joints + head pan)
- GM3506-2: 9 units (ankle joints + head tilt)

Total: 26 motors. Please confirm pricing, availability,
and shipping options to Netherlands (Europe).

Best regards,
Berechja Kerkdijk
Chrystal Moon Base
```

---

## Hamamatsu — Spectroscopy Sensors

**Website:** hamamatsu.com / eu.hamamatsu.com
**Products:** C12880MA · C15713

```
Subject: Technical inquiry — C12880MA and C15713 for space robotics

Dear Hamamatsu Europe,

I am developing a lunar surface robot prototype with
integrated spectroscopic capability for real-time
regolith analysis (ISRU — In-Situ Resource Utilization).

I am interested in:
1. C12880MA micro-spectrometer (340-850nm) — 2 units
   For micro-LIBS elemental analysis
2. C15713 MEMS-FPI spectrometer (SWIR) — 2 units
   For water-ice detection (1490-1850nm)

Project: Chrystal Moon Base (ESA OSIP qualified open-source)
Please advise on pricing, availability, and whether
evaluation units are available for research projects.

Kind regards,
Berechja Kerkdijk
info@chrystalmoonbase.com
chrystalmoonbase.com
```

---

## Ximea — HSI Hyperspectral Camera

**Website:** ximea.com
**Product:** xiSpec series (Imec mosaic sensor)

```
Subject: Research inquiry — xiSpec hyperspectral camera

Dear Ximea,

I am building a lunar robotics demonstrator with onboard
hyperspectral imaging for real-time mineralogical mapping
of Peary Crater highland regolith.

I am interested in the xiSpec USB3 camera with
Imec snapshot mosaic sensor (~470-900nm range).
The camera will be mounted on the robot head,
interfaced directly to an NVIDIA Jetson Orin Nano.

Project: Chrystal Moon Base (github.com/ChrystalMoonBase)
ESA OSIP qualified — open hardware (CERN-OHL-S) & open docs (CC0)

Please advise on the most suitable model for this application,
pricing, and whether academic/research pricing applies.

Best regards,
Berechja Kerkdijk
info@chrystalmoonbase.com
```

---

## Kimya / Nanovia — PEEK-CF Filament

**Website:** kimya.fr / nanovia.tech
**Product:** PEEK-CF 1.75mm 500g

```
Subject: Order — PEEK-CF filament for lunar robot prototype

Hello,

I am printing structural components for a lunar surface robot
prototype in PEEK-CF. I need filament with verified low outgassing
(TML <0.1%) for eventual vacuum chamber testing.

Quantity needed: 8 × 500g rolls PEEK-CF 1.75mm

Please confirm:
- TML/CVCM outgassing data (ASTM E595)
- Recommended print temperature and chamber requirements
- Shipping to Netherlands

Project website: chrystalmoonbase.com

Best regards,
Berechja Kerkdijk
```

---

## Xometry Europe — PEEK-CF Print Service

**Website:** xometry.eu
**Use:** Voor onderdelen die eigen printer nog niet aankan

```
Materiaal: PEEK-CF of PEEK (opgeven welke beschikbaar)
Tolerantie: ±0.1mm op koppelingsgaten en laserboringen
Oppervlak: Ra ≤ 1.6μm op alle glijdende vlakken
Kwantiteit: 1 stuk per order (prototype)

Bestanden uploaden: .STL of .STEP uit cad/ map
Notitie bij bestelling:
"Lunar robotics research prototype — Chrystal Moon Base
Vacuum-rated application — geen nareiniging met waterige vloeistoffen"
```

---

## Intamsys — PEEK Printer (optie B)

**Website:** intamsys.com
**Product:** FUNMAT HT Enhanced

```
Subject: Sales inquiry — FUNMAT HT Enhanced for PEEK printing

Dear Intamsys,

I am developing a lunar surface robot prototype requiring
PEEK-CF structural components. I am evaluating the
FUNMAT HT Enhanced as my primary production printer.

Project: Chrystal Moon Base — ESA OSIP qualified open-source
lunar construction robot. Full details: chrystalmoonbase.com

Please provide:
- Current pricing and lead time for Netherlands
- Recommended filament for PEEK-CF
- Training/support options

Kind regards,
Berechja Kerkdijk
info@chrystalmoonbase.com
```

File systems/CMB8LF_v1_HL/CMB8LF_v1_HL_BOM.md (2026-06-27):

# CMB8LF-S1-HL — Bill of Materials (delta against standard)

**Variant:** Head-less · **Base:** `../CMB8LF_v1/CMB8LF_v1_BOM_v6.md`
**CC0 · Chrystal Moon Base · 2026**

This BOM lists **only what differs** from the standard prototype BOM. Everything not listed
here (legs, motors, moteus, CAN bus, Jetson, power, laser-palm, coupling, structure, filament)
is **identical and shared** — order it from `../CMB8LF_v1/CMB8LF_v1_BOM_v6.md`. The working
laser-palm is unchanged and stays in the front leg.

---

## What changes: the sensing layer only

### REMOVED (vs standard head)

| Onderdeel | Aantal | Prijs/st | Totaal | Reden |
|---|---|---|---|---|
| WS2812B "RGB ogen" | 2 | €1 | −€2 | Cosmetic eyes — human affectation, no function |
| Pan-as servo (kop) | 1 | €12 | −€12 | No head to pan |
| Tilt-as servo (kop) | 1 | €12 | −€12 | No head to tilt |
| Pan/tilt lager + as | 1 | €8 | −€8 | Mechanism deleted |
| **Verwijderd subtotaal** | | | **−€34** | |

### ADDED (body-integrated sensing)

| Onderdeel | Aantal | Prijs/st | Totaal | Bus | Positie |
|---|---|---|---|---|---|
| Surround override camera (wide-angle, OV5647 module) | 4 | €12 | €48 | CSI/USB → Jetson | Body 0°/90°/180°/270° |
| CSI multiplexer (Arducam 4-ch) | 1 | €45 | €45 | → Jetson | Combine cameras |
| Sacrificial optical window (sapphire ⌀30mm) | 4 | €9 | €36 | — | Work + spare set (replaceable) |
| Window clip frame (geprint PEEK-CF) | 2 | — | — | — | CAD `sensor_mounts` |
| Work-sensor pod (geprint PEEK-CF) | 1 | — | — | — | CAD `sensor_mounts` |
| LiDAR top riser + cap (geprint) | 1 | — | — | — | CAD `body_chassis` HL |
| **Toegevoegd subtotaal** | | | **€129** | | |

### RELOCATED (same parts, new place — no cost change)

These are the **same items** as the standard sensor BOM, just mounted in the body instead of a
head. They are **not re-ordered** — they move:
- RPLIDAR A1M8 (€90) → body top riser
- Pi Camera 3 NoIR (€28) → front-lobe work window (also feeds override)
- FLIR Lepton 3.5 (€180) → front-lobe work window
- 2× VL53L1X ToF (€10) → body sides
- 6× IR LED array + 10 W spotlight → front-lobe illumination ring
- FSO laser comm → body top-front
- BNO055 IMU (€8) → body (unchanged location, already internal)

---

## Net cost effect

| | Bedrag |
|---|---|
| Standard prototype EINDTOTAAL (excl. printer) | ~€7.497 |
| − removed (eyes, pan/tilt) | −€34 |
| + added (surround cams, mux, windows) | +€129 |
| **Head-less EINDTOTAAL (excl. printer)** | **~€7.592** |

The head-less variant is **~€95 more** than the standard build — the cost of four surround
cameras + multiplexer + replaceable windows, minus the deleted pan/tilt and cosmetic eyes. In
return it removes a detachable-head coupling, two servos and a moving mechanism (fewer failure
points), and gives the override engineer all-round vision.

---

## Ordering note

Order the **entire standard BOM** (`../CMB8LF_v1/CMB8LF_v1_BOM_v6.md`) **except** the pan/tilt
servos and the WS2812B eyes, then add the four "ADDED" line items above. All sensor parts that
the standard BOM lists as "Hoofd" (head) position are kept — they simply mount in the body per
`docs/HEADLESS_DESIGN.md`.

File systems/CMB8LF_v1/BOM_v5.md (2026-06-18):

# CMB8LF-S1 — Definitieve Boodschappenlijst v5 (Ultimate)
**Hardware-veilig · EMI-gescheiden · Vacuümklaar · Thermisch bewust**
**Alle bekende ontwerprisico's geadresseerd**
**CC0 — Chrystal Moon Base 2026**

---

## Wat v5 toevoegt ten opzichte van v4.1

| Probleem | Bron | Fix in v5 |
|---|---|---|
| Software-only stroomlimiet — hardware trip ontbrak | ChatGPT | PTC polyfuse per buck output |
| LiPo packs parallel → equalization currents, thermische doorloop | ChatGPT | Strict domain separation — packs nooit parallel |
| I2C EMI van buck-switching op servo-kabels | ChatGPT | Twee I2C bussen: kritiek / monitoring gescheiden |
| Geen hardware noodstop | — | E-stop knop + relaismodule per robot |
| TPU 95A outgassing in vacuum | ChatGPT | PEBA als vacuümfase-vervanging gedocumenteerd |
| Loctite 243 borderline vacuum-safe | ChatGPT | Master Bond EP21TDCHT als vacuüm-alternatief |
| Servo horns bij mechanisch i.p.v. actuatie | Meta | Verplaatst naar TinyTronics — actuatie categorie |

---

## Power Architectuur v5 — Strict Domain Separation

```
┌─────────────────────────────────────────────────────────────────┐
│ ROBOT 1                                                         │
│                                                                 │
│  [Pack 1 · 3S 5000mAh]                                         │
│       │                                                         │
│  [BMS 40A] ── [Anti-spark XT60]                                 │
│       │                                                         │
│       ├── [PTC 30A] ── [Buck A · 7.4V/20A] ── DS3240 ×4        │
│       │                                         DS3225 ×4       │
│       │                (poten 1, 2, 3, 4)                       │
│       │                                                         │
│       └── [PTC 15A] ── [Buck C · 6.0V/10A XL4016] ── DS3218 ×8│
│                                                                 │
│  [Pack 2 · 3S 5000mAh]                                         │
│       │                                                         │
│  [BMS 40A] ── [Anti-spark XT60]                                 │
│       │                                                         │
│       ├── [PTC 30A] ── [Buck B · 7.4V/20A] ── DS3240 ×4        │
│       │                                         DS3225 ×4       │
│       │                (poten 5, 6, 7, 8)                       │
│       │                                                         │
│       └── [PTC 15A] ── [Buck D · 5V/10A] ── Pi 5               │
│                                              Pico W ×2          │
│                                              PCA9685 ×2         │
│                                              Sensoren           │
│                                              RPLIDAR            │
│                                                                 │
│  [E-STOP knop] ─── [Relaismodule] ─── snijdt Pack 1 + Pack 2   │
└─────────────────────────────────────────────────────────────────┘

KRITISCHE REGEL: Pack 1 en Pack 2 worden NOOIT parallel geschakeld.
Geen gemeenschappelijke + verbinding. Elk pack voedt eigen domein.
Equalization currents: fysiek onmogelijk.
```

### Stroomberekening v5 (per buck, worst-case)

| Rail | Buck | Max servo's | Worst-case stroom | Buck rating | Marge |
|---|---|---|---|---|---|
| 7.4V Buck A | 4× DS3240 + 4× DS3225 | 6 (software) | 16.8A | 20A | ✅ +3.2A |
| 7.4V Buck B | 4× DS3240 + 4× DS3225 | 6 (software) | 16.8A | 20A | ✅ +3.2A |
| 6.0V Buck C | 8× DS3218 | 4 (software) | 7.2A | 8-9A XL4016 | ✅ +1A |
| 5V Buck D | Pi5 + Pico's + sensoren | — | ~5A | 10A | ✅ +5A |
| PTC trip (7.4V) | — | Hardware | 30A trip | 30A PTC | ✅ |
| PTC trip (6V/5V) | — | Hardware | 15A trip | 15A PTC | ✅ |

---

## I2C Bus Architectuur v5

```
Pico W (per robot, 2 stuks):

  I2C Bus 0 (GP4/GP5) — SERVO CONTROL (hoge prioriteit)
    ├── PCA9685 board A  0x40  (servo PWM poten 1-4)
    └── PCA9685 board B  0x41  (servo PWM poten 5-8)

  I2C Bus 1 (GP6/GP7) — MONITORING (gescheiden van buck noise)
    ├── INA226 buck A    0x44  (7.4V rail A stroom)
    ├── INA226 buck B    0x45  (7.4V rail B stroom)
    ├── INA226 buck C    0x46  (6.0V rail stroom)
    ├── INA226 buck D    0x47  (5V rail stroom)
    └── TMP117 ×2        0x48/0x49 (frame temperatuur)

  1-Wire (GP22) — THERMISCH
    └── DS18B20 ×8 (servo cluster temperatuur)

Pi 5 (per robot):

  I2C Bus 1 (GPIO 2/3) — NAVIGATIE SENSOREN
    ├── BNO055 IMU        0x28
    └── VL53L1X ToF ×2   0x29/0x2A

  UART (GPIO 14/15) — LIDAR
    └── RPLIDAR A1M8

  CSI — CAMERA
    └── Pi Camera Module 3

EMI-maatregel: Twisted-pair dupont kabels voor I2C Bus 1.
Ferrietkern op I2C Bus 1 kabels bij entree Pico W behuizing.
```

---

## Volledige BOM v5

### 1. Brein & Compute — €258

| Onderdeel | Aantal | Prijs/st | Totaal |
|---|---|---|---|
| Raspberry Pi 5 8GB | 2 | €85 | €170 |
| Raspberry Pi Pico W | 4 | €10 | €40 |
| PCA9685 16-kanaals servo driver | 4 | €8 | €32 |
| MicroSD 32GB | 2 | €8 | €16 |
| **Subtotaal** | | | **€258** |

### 2. Actuatie & Servo-toebehoren — €751

| Onderdeel | Aantal | Prijs/st | Totaal |
|---|---|---|---|
| DS3240 35kg/cm — heup — 7.4V | 16 | €18 | €288 |
| DS3225 25kg/cm — bovenbeen — 7.4V | 16 | €14 | €224 |
| DS3218 20kg/cm — onderbeen — 6.0V | 16 | €12 | €192 |
| Servo verlengkabels 30cm JST-SM | 30 | €0.50 | €15 |
| Servo horns assortiment (DS3240/DS3225/DS3218) | 4 sets | €8 | €32 |
| **Subtotaal** | | | **€751** |

### 3. Power Systeem — €445

| Onderdeel | Aantal | Prijs/st | Totaal | Noot |
|---|---|---|---|---|
| LiPo 3S 5000mAh 35C met XT60 | 4 | €25 | €100 | 2 per robot, nooit parallel |
| 3S 40A BMS | 4 | €8 | €32 | 1 per pack |
| Buck 7.4V/20A instelbaar | 8 | €12 | €96 | 2 per robot (A+B) |
| Buck 6.0V/10A instelbaar XL4016/MP4569 | 4 | €10 | €40 | 8-9A continu vereist |
| Buck 5V/10A | 2 | €12 | €24 | 1 per robot |
| **PTC polyfuse 30A (Littelfuse RGEF3000)** | **8** | **€2.50** | **€20** | **Per 7.4V buck output** |
| **PTC polyfuse 15A (Littelfuse RGEF1500)** | **8** | **€1.50** | **€12** | **Per 6V + 5V buck output** |
| **E-stop drukknop (NC, 22mm, rood)** | **2** | **€5** | **€10** | **Per robot — hardware noodstop** |
| **Relaismodule 30A (voor e-stop)** | **2** | **€6** | **€12** | **Snijdt beide packs tegelijk** |
| XT60 connector paren (M+V) | 20 | €0.60 | €12 | |
| XT60 Y-splitter kabel (1× naar 2×) | 4 | €4 | €16 | Pack → 2 bucks per domein |
| XT30 connector paren (M+V) | 10 | €0.40 | €4 | |
| Anti-spark XT60 | 4 | €3 | €12 | |
| LiPo balanslader 3S (ISDT Q6 Plus) | 1 | €45 | €45 | |
| Silicoon kabel 14AWG rood + zwart 2m | 1 set | — | €12 | |
| Silicoon kabel 18AWG rood + zwart 2m | 1 set | — | €8 | |
| **Ferrietkern ringen (I2C EMI)** | **10** | **€0.50** | **€5** | **Op I2C monitoring bus** |
| **Subtotaal** | | | **€460** | |

### 4. Elektronica Extras — €60

| Onderdeel | Aantal | Prijs/st | Totaal |
|---|---|---|---|
| 5V 650nm lasermodule | 2 | €5 | €10 |
| Logic-level MOSFET IRF520 | 2 | €5 | €10 |
| Neodymium 10×2mm (EPM) | 20 | €0.50 | €10 |
| Neodymium 5×2mm (EPM) | 40 | €0.30 | €12 |
| Dupont jumper wires assortiment | 6 sets | €3 | €18 |
| Elektrolytische condensator 1000µF 16V | 6 stuks | €0.50 | €3 |
| **Subtotaal** | | | **€63** |

### 5. Sensoren — €374

| Onderdeel | Aantal | Prijs/st | Totaal | I2C bus |
|---|---|---|---|---|
| RPLIDAR A1M8 (5V, 360°) | 2 | €90 | €180 | UART |
| BNO055 9-assige IMU | 4 | €8 | €32 | Pi5 Bus 1 |
| Pi Camera Module 3 (12MP) | 2 | €25 | €50 | CSI |
| VL53L1X Time-of-Flight | 4 | €5 | €20 | Pi5 Bus 1 |
| HC-SR04 ultrasoon | 4 | €2 | €8 | GPIO |
| DS18B20 temperatuursensor | 8 | €2.50 | €20 | 1-Wire |
| TMP117 precisie temperatuursensor | 4 | €4.50 | €18 | Pico Bus 1 |
| INA226 **met ADDR-pin** | 8 | €4 | €32 | Pico Bus 1 |
| TCRT5000 IR reflectie | 4 | €1 | €4 | GPIO |
| BMP280 druk + temperatuur | 2 | €2 | €4 | Pi5 Bus 1 |
| BH1750 lichtintensiteit | 2 | €1.50 | €3 | Pi5 Bus 1 |
| KY-038 geluidssensor | 2 | €1.50 | €3 | ADC |
| **Subtotaal** | | | **€374** | |

### 6. Mechanische Onderdelen — €153

| Onderdeel | Aantal | Prijs/st | Totaal | Noot |
|---|---|---|---|---|
| M3 bouten assortiment RVS (200 stuks) | 1 doos | — | €12 | |
| M2 bouten assortiment RVS (100 stuks) | 1 doos | — | €8 | |
| M3 nyloc moeren (100 stuks) | 1 pak | — | €6 | |
| M2 nyloc moeren (50 stuks) | 1 pak | — | €4 | |
| F688-2RS RVS kogellager (8×16×5mm) | 40 stuks | €2 | €80 | Heup + knie pivot only |
| M3 messing heat-set inserts (100 stuks) | 1 pak | — | €8 | |
| M2 messing heat-set inserts (50 stuks) | 1 pak | — | €6 | |
| M3 borgpennen/cilinderstiften 3×10mm | 20 stuks | €0.30 | €6 | |
| Klittenband 20mm zwart (2m) | 1 | — | €5 | |
| Krimpkous assortiment | 1 set | — | €8 | |
| Loctite 243 blauw | 1 tube | — | €10 | Fase 1 only — zie vacuüm noten |
| **Subtotaal** | | | **€153** | |

**Kogellager plaatsing (geoptimaliseerd):**
Alleen op heup rotatie-as en kniepivot — niet op secundaire koppelingen.
Per poot: 2 lagers. 8 poten × 2 robots × 2 = 32 lagers. 40 besteld = 8 reserve ✓.
Resultaat: −15% gewicht, −10% servo-belasting t.o.v. lager-op-alle-joints.

### 7. Filamenten — €449

| Materiaal | Hoeveelheid | Prijs | Totaal | Gebruik | Vacuum |
|---|---|---|---|---|---|
| Prusament PC Space Grade Black | 7 × 850g | €48/rol | €336 | Chassis, frame, panelen | ✅ |
| PA12-CF | 1 kg | €65 | €65 | Bajonet, sockets (0.2mm, 100% infill) | ✅ |
| TPU 95A zwart | 1 kg | €30 | €30 | Sneeuwschoenen fase 1 | ⚠️ fase 1 only |
| PLA+ | 1 kg | €18 | €18 | Maatcontrole — NOOIT in eindrobot | ❌ |
| **Subtotaal** | | | **€449** | | |

**Vacuümfase filament upgrade (apart bestellen bij vacuümkamer sessie):**
- TPU 95A → **PEBA** (Polyether block amide, bijv. Filaflex PEBA of Arnitel) — €80-120/kg
- PLA volledig uit systeem verwijderen voor vacuümtest

### 8. Gereedschap — €184

| Onderdeel | Prijs |
|---|---|
| Soldeerbout 65W (Hakko FX-888D of gelijkw.) | €50 |
| Soldeertin 60/40 0.8mm 100g | €8 |
| Vloeistof flux | €6 |
| Digitale schuifmaat 150mm | €15 |
| Precisie schroevendraaierset magnetisch | €15 |
| Heat-set insert tool M2+M3 | €12 |
| Nippeltang + draadstriptang | €15 |
| Isopropanol 99% 250ml | €6 |
| Anti-statische tweezertjes | €8 |
| Multimeter (Fluke 101 of gelijkw.) | €25 |
| Plastic snijmat A4 | €6 |
| Set kleine vijlen 5 stuks | €10 |
| Cyanoacrylaat + activator | €8 |
| **Subtotaal** | **€184** |

### 9. Thermische Interface & Vacuümcoating — €170

| Onderdeel | Aantal | Prijs | Totaal | ASTM E595 |
|---|---|---|---|---|
| Bergquist GAP PAD HC5.0 100×100mm 1.0mm | 2 platen | €25 | €50 | TML 0.05% ✅ |
| Bergquist GAP PAD HC3.0 100×100mm 0.5mm | 2 platen | €15 | €30 | TML 0.11% ✅ |
| MasterSil 323AO-LO 50g kit | 1 | €40 | €40 | ✅ |
| Aeroglaze Z306 low-outgassing mat zwart | 1 spuitbus | €50 | €50 | ✅ |
| **Subtotaal** | | | **€170** | |

**Vacuümfase lijm upgrade:**
- Loctite 243 → **Master Bond EP21TDCHT** (vacuum-rated structural adhesive)
- Bestellen bij vacuümkamersessie planning

### 10. 3D-Printer — €739

| Onderdeel | Prijs |
|---|---|
| QIDI Tech Plus4 | €699 |
| Reserve PEI-bouwplaat | €25 |
| Hardstalen nozzle 0.4mm + 0.6mm | €15 |
| **Subtotaal** | **€739** |

---

## Budget Evolutie

| Versie | Totaal | Toevoeging |
|---|---|---|
| v2 | €2.937 | Power architectuur gecorrigeerd |
| v3 | €3.435 | PC Space Grade, thermische pads |
| v4 | €3.531 | Dubbele buck, INA226 ADDR, servo horns |
| v4.1 | €3.637 | Servo horns → TinyTronics (Meta fix) |
| **v5** | **€3.711** | **PTC fuses, e-stop, EMI ferriet, XT60 Y-splitter** |
| Buffer 3% | €111 | |
| **Eindtotaal** | **€3.822** | |

---

## Firmware Aanpassingen v5

### Dual I2C bus (main.py update)

```python
# CMB8LF v5 — I2C bus scheiding
from machine import I2C, Pin

# Bus 0: servo PWM — hoge prioriteit, laag noise-risico
i2c_servo = I2C(0, sda=Pin(4), scl=Pin(5), freq=400_000)
# PCA9685-A (0x40), PCA9685-B (0x41)

# Bus 1: monitoring — gescheiden van buck-switching EMI
i2c_monitor = I2C(1, sda=Pin(6), scl=Pin(7), freq=100_000)
# INA226 ×4 (0x44-0x47), TMP117 ×2 (0x48-0x49)
# Lagere freq (100kHz) = beter EMI-gedrag op lange kabels
```

### Hardware e-stop interrupt (main.py update)

```python
# Hardware noodstop — onafhankelijk van software current limit
ESTOP_PIN = 14   # NC schakelaar — LOW = noodstop

estop = Pin(ESTOP_PIN, Pin.IN, Pin.PULL_UP)

def estop_handler(pin):
    # Vanuit interrupt: alleen flag — geen I2C
    failsafe._triggered = True

estop.irq(trigger=Pin.IRQ_FALLING, handler=estop_handler)
# Bij indrukken knop → failsafe actief → main loop zet alles uit
```

### Power domain check bij boot

```python
# Controleer bij boot of beide packs los van elkaar zijn
# Meting via INA226: als bus A en bus B exact gelijke spanning
# tonen na startup → waarschuwing (mogelijk per ongeluk parallel)
def check_domain_isolation():
    v_a = ina_buck_a.voltage_v()
    v_b = ina_buck_b.voltage_v()
    if abs(v_a - v_b) < 0.05:   # <50mV verschil
        print("[WARN] Packs mogelijk parallel — controleer bedrading")
    else:
        print(f"[INIT] Domain isolatie OK: A={v_a:.2f}V B={v_b:.2f}V")
```

---

## Vacuümgereedheid Checklist

| Onderdeel | Fase 1 (lucht) | Fase 2 (vacuum) | Fix |
|---|---|---|---|
| PC Space Grade | ✅ | ✅ | — |
| PA12-CF | ✅ | ✅ | — |
| TPU 95A | ✅ | ⚠️ | Vervangen door PEBA |
| PLA+ | test only | ❌ | Volledig verwijderen |
| Silicoon kabel | ✅ | ✅ | — |
| Loctite 243 | ✅ | ⚠️ | Vervangen door EP21TDCHT |
| Bergquist pads | ✅ | ✅ | — |
| MasterSil 323AO-LO | ✅ | ✅ | — |
| Aeroglaze Z306 | ✅ | ✅ | — |
| Neodymium magneten | ✅ | ✅ | — |
| Lagers F688-2RS (droog) | ✅ | ⚠️ | MoS₂ droog smeermiddel |

---

## Wat er nu niet meer te verbeteren valt

| Punt | Status |
|---|---|
| Hardware stroombeveiliging | ✅ PTC per buck output |
| LiPo parallel risico | ✅ Strict domain separation |
| Software current limiting | ✅ DualRailServoLimiter + 3 sub-rails |
| I2C EMI scheiding | ✅ Twee bussen + ferrietkern |
| Hardware noodstop | ✅ E-stop knop + relais |
| Thermisch beheer | ✅ ThermalManager + cooldown posture |
| Vacuümvoorbereiding | ✅ ASTM E595 pads, coating, materiaalplan |
| Adresconflict INA226 | ✅ ADDR-pin 0x44-0x47 |
| Servo duty-cycle | ✅ MAX_SIMUL_7V4_PER_BUCK = 6 |
| Kogellager plaatsing | ✅ Heup + knie only |
| Filament vacuümplan | ✅ PEBA als TPU-vervanging gedocumenteerd |
| Slicer instellingen | ✅ PRINT_SETTINGS.md (Gemini) |
| Power-up volgorde | ✅ VACUUM_PREP.md (Meta) |
| Thermische pads | ✅ ASTM E595, 2 platen, 60×60mm Pi5 |

---

*CMB8LF-S1 — Boodschappenlijst v5 — Ultimate*
*Meta · DeepSeek · Gemini · ChatGPT · Claude — alle input verwerkt*
*CC0 — Chrystal Moon Base 2026*

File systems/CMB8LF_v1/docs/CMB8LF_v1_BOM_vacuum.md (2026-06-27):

# CMB8LF-S1 — Bill of Materials v6
## Chrystal Moon Base · 8 Legged Freaks · Volledige Revisie
**Brushless · 24V Gedistribueerd · CAN Bus · Vacuum-Proof**
**CC0 · Berechja Kerkdijk · 2026**

---

## Wat v6 verandert ten opzichte van v5

| Verandering | Reden |
|---|---|
| Alle hobby servos → brushless BLDC + moteus | Precisie · koppelregeling · 24V native |
| PCA9685 → CAN bus (USB-CAN adapter) | Één bus voor alle 26 motoren |
| Centrale batterij → 25 gedistribueerde nodes | Fault tolerant · gewicht verdeling |
| PC Space Grade → PEEK-CF | Hogere temperatuur · vacuum betere outgassing |
| Laser 650nm symbolisch → 808nm/976nm echt | Echt glaspoeder smelten |
| Tripod gait → Wave gait | Maximale stabiliteit |
| Standaard lagers → Si₃N₄ keramisch | Vacuum-proof · smeervrij |

---

## KOSTENSTRUCTUUR PER MODULE

```
MODULE               KOSTEN      PRIORITEIT
─────────────────────────────────────────────
1 standaard been     ~€365       Eerst bouwen
1 grijper been       ~€520       Tweede been
Hoofd                ~€310       Derde
Body + compute       ~€480       Laatste
Printer (éénmalig)   ~€700-4500  Zie sectie 10
─────────────────────────────────────────────
TOTAAL ROBOT         ~€3.800     excl. printer
Per maand (1 been)   ~€365-520
```

---

## 1. COMPUTE & AI — €285

| Onderdeel | Aantal | Prijs/st | Totaal | Functie |
|---|---|---|---|---|
| Raspberry Pi 5 8GB | 1 | €90 | €90 | Hoofd AI · navigatie |
| Raspberry Pi Pico W | 2 | €10 | €20 | CAN master · safety |
| RP2350 module | 26 | €4 | €104 | Mini AI per segment + hoofd |
| MicroSD 64GB | 1 | €10 | €10 | Pi5 opslag |
| USB-CAN adapter (Canable) | 1 | €25 | €25 | Pi5 → CAN bus |
| USB hub 4-poort (Pi5) | 1 | €15 | €15 | USB devices Pi5 |
| Kleine breadboard PCB's | 10 | €2 | €20 | Verbindingen compute bay |
| **Subtotaal** | | | **€284** | |

---

## 2. MOTOREN & CONTROLLERS — €2.180

### 2A. moteus r4.11 CAN Controllers

| Onderdeel | Aantal | Prijs/st | Totaal | Noot |
|---|---|---|---|---|
| mjbots moteus r4.11 | 26 | €85 | €2.210 | 24 been + 2 hoofd |

> **BOUWTIP**: Bestel moteus controllers gefaseerd — 3 per been × 8 benen.
> Eerste bestelling: 3 stuks voor been 1. Zo spreidt je de kosten.

### 2B. BLDC Motoren

| Onderdeel | Aantal | Prijs/st | Totaal | Positie |
|---|---|---|---|---|
| iPower GM5208-150T | 8 | €28 | €224 | Heup (coxa) — hoogste koppel |
| iPower GM4108H-120T | 10 | €22 | €220 | Knie (femur) + hoofd pan |
| iPower GM3506-2 | 8 | €18 | €144 | Enkel (tibia) + hoofd tilt |
| **Subtotaal motoren** | | | **€588** | |

### 2C. Encoder (ingebouwd in moteus — geen extra nodig)
*De moteus r4.11 heeft AS5047P encoder interface ingebouwd.*
*Encoders zijn inbegrepen in de moteus prijs.*

### 2D. Grijper Vinger Servos (klein — brushless te groot)

| Onderdeel | Aantal | Prijs/st | Totaal | Noot |
|---|---|---|---|---|
| MG90S mini servo | 8 | €4 | €32 | 4 vingers × 2 grijper benen |
| Servo driver PCA9685 | 2 | €6 | €12 | 1 per grijper been |
| **Subtotaal grijpers** | | | **€44** | |

---

## 3. BATTERIJEN & POWER — €480

### 3A. Segment Batterijen (25 nodes)

> **Waarom 25 nodes?** Ontwerpprincipe: **elk bewegend segment heeft zijn eigen kleine
> batterij** in plaats van één centrale accu. Valt één node uit, dan verliest de robot
> alleen dat segment — de rest blijft werken (fault-tolerance + gewichtsverdeling). Het
> getal volgt uit de segment-telling (~8 poten met hun been-segmenten + body), niet uit
> het aantal poten. **25 is een schaalbare werkwaarde**: het definitieve aantal hangt af
> van het uiteindelijke aantal onafhankelijke segmenten en wordt door engineering/
> professionals bepaald. Het principe (één node per segment) staat vast; het exacte
> aantal niet.

| Onderdeel | Aantal | Prijs/st | Totaal | Noot |
|---|---|---|---|---|
| 16340 Li-Ion 700mAh (losse cel) | 150 | €2.50 | €375 | 6 per segment × 25 |
| 6S mini BMS 5A | 24 | €6 | €144 | 1 per been-segment |
| Nikkelstrip 0.15mm × 8mm | 5m | €8 | €40 | Celverbindingen |
| **Subtotaal segment power** | | | **€559** | |

### 3B. Body Batterij

| Onderdeel | Aantal | Prijs/st | Totaal | Noot |
|---|---|---|---|---|
| LiPo 4S 5000mAh XT60 | 1 | €45 | €45 | Body electronics |
| 4S 30A BMS | 1 | €10 | €10 | Body batterij |
| Buck 5V/10A | 2 | €10 | €20 | Pi5 + Pico W power |
| Buck 3.3V/3A | 6 | €5 | €30 | RP2350 per segment |
| E-stop knop NC 22mm rood | 1 | €5 | €5 | Hardware noodstop |
| Relaismodule 30A | 1 | €8 | €8 | E-stop schakeling |
| XT60 connectoren | 20 | €0.80 | €16 | Power verbindingen |
| Anti-spark XT60 | 2 | €4 | €8 | Veilig aansluiten |
| Lader 4S balanceer (ISDT Q6) | 1 | €45 | €45 | Body lader |
| Lader 6S balanceer | 1 | €55 | €55 | Segment lader |
| **Subtotaal body power** | | | **€242** | |

---

## 4. CAN BUS & BEDRADING — €95

| Onderdeel | Aantal | Prijs/st | Totaal | Noot |
|---|---|---|---|---|
| Twisted pair CAN kabel 26AWG | 20m | €3/m | €60 | H+L door alle botten |
| 120Ω CAN terminatieweerstand | 20 | €0.30 | €6 | 2 per CAN lijn |
| JST-GH 4-pin (CAN + power door koppeling) | 30 | €1 | €30 | Per koppelingsinterface |
| Kabelgoten PEEK-CF snap | geprint | — | — | Ontwerp in CAD |
| **Subtotaal CAN** | | | **€96** | |

---

## 5. KOPPELINGSSYSTEEM — €320

### Bistabiele Magneetkoppeling × 9 (8 benen + hoofd)

| Onderdeel | Aantal | Prijs/st | Totaal | Noot |
|---|---|---|---|---|
| NdFeB N52 magneetring ⌀40mm | 9 | €12 | €108 | Permanente vergrendeling |
| Release spoel (custom wikkeling) | 9 | €8 | €72 | 50ms puls ontgrendeling |
| Si₃N₄ keramisch kogellager ⌀30mm | 18 | €15 | €270 | 2 per koppeling |
| Vergoud pogo pin set 5-pins | 9 | €8 | €72 | Power + CAN contact |
| Hall sensor A3144 | 9 | €1 | €9 | Vergrendeld/los detectie |
| PEEK-CF geleidingsneus (geprint) | 9 | — | — | CAD ontwerp |
| MoS₂ dry film spray 400ml | 2 | €25 | €50 | ALLE bewegende vlakken |
| **Subtotaal koppeling** | | | **€581** | |

---

## 6. SENSOREN — €375

| Onderdeel | Aantal | Prijs/st | Totaal | Bus | Positie |
|---|---|---|---|---|---|
| RPLIDAR A1M8 | 1 | €90 | €90 | UART → Pi5 | Hoofd |
| Pi Camera 3 NoIR | 1 | €28 | €28 | CSI → Pi5 | Hoofd |
| FLIR Lepton 3.5 | 1 | €180 | €180 | SPI → Pi5 | Hoofd |
| BNO055 IMU | 1 | €8 | €8 | I2C → Pi5 | Hoofd |
| VL53L1X ToF | 2 | €5 | €10 | I2C → Pi5 | Hoofd links+rechts |
| MLX90614ESF | 2 | €8 | €16 | I2C → RP2350 | Palm ×2 |
| TMP117 precisie temp | 26 | €4 | €104 | I2C → RP2350 | Per segment |
| INA226 stroom monitor | 10 | €4 | €40 | I2C → Pico W | Power rails |
| **Subtotaal sensoren** | | | **€476** | | |

---

## 7. LASER PALM SYSTEEM — €180 (×2 palmen)

| Onderdeel | Aantal | Prijs/st | Totaal | Noot |
|---|---|---|---|---|
| Laserdiode 808nm 2W TO-56 | 2 | €35 | €70 | L1 sinter (1 per palm) |
| Laserdiode 976nm 1W TO-56 | 2 | €25 | €50 | L2 anneal (1 per palm) |
| Asferische collimeer lens 4.51mm EFL | 2 | €18 | €36 | L1 focus |
| Defocus barrel optiek | 2 | €12 | €24 | L2 brede spot |
| Messing lensbarrel M5 | 4 | €6 | €24 | Houder per lens |
| CC laser driver switching 2A | 2 | €15 | €30 | L1 driver |
| CC laser driver PWM 1A | 2 | €12 | €24 | L2 driver |
| AL6061 palmkern 65×50×40mm | 2 | €25 | €50 | CNC of printservice |
| OD4+ laserbril 808+976nm | 1 | €45 | €45 | VERPLICHT · gedeeld |
| **Subtotaal laser** | | | **€353** | |

---

## 8. MECHANISCH — €175

| Onderdeel | Prijs | Noot |
|---|---|---|
| M3 RVS bouten assortiment 300 stuks | €14 | Alle assemblages |
| M2 RVS bouten assortiment 150 stuks | €9 | Kleine componenten |
| M3 messing heat-set 100 stuks | €8 | PEEK-CF verbindingen |
| M2 messing heat-set 60 stuks | €6 | Kleine prints |
| M3 nyloc moeren 100 stuks | €6 | Vibratie-vast |
| Si₃N₄ keramische lagers F688 ×40 | €80 | Heup + knie gewrichten |
| Titaan M3 bouten 50 stuks | €25 | Exterieur (non-magnetisch) |
| Krimptube assortiment | €8 | Alle verbindingen |
| Isopropanol 99% 500ml | €10 | Reiniging voor assemblage |
| Thermische pasta vacuüm-grade | €12 | Motor → structuur |
| **Subtotaal** | **€178** | |

---

## 9. THERMISCH & VACUUM COATING — €145

| Onderdeel | Prijs | ASTM E595 | Noot |
|---|---|---|---|
| Bergquist GAP PAD HC5.0 200×200mm | €60 | TML 0.05% ✅ | Motor → kern |
| Silica aerogel blanket 300×300×6mm | €40 | ✅ | Thermische isolatie |
| Aeroglaze Z306 mat zwart spuitbus | €50 | ✅ | Buitencoating |
| MasterSil 323AO-LO 50g | €40 | ✅ | Vacuum adhesief |
| **Subtotaal** | **€190** | | |

---

## 10. VERLICHTING — €65

| Onderdeel | Aantal | Prijs | Totaal |
|---|---|---|---|
| WS2812B LED strip 60LED/m | 2m | €12 | €24 |
| 850nm IR LED 1W | 6 | €4 | €24 |
| 10W LED spotlight module | 1 | €8 | €8 |
| IR LED driver MOSFET | 3 | €3 | €9 |
| **Subtotaal** | | | **€65** | |

---

## 11. GEREEDSCHAP (éénmalig) — €185

| Onderdeel | Prijs |
|---|---|
| Soldeerbout 65W temperatuurgeregeld | €50 |
| Fijn soldeertin 60/40 0.6mm | €10 |
| Digitale schuifmaat 0.01mm | €20 |
| Heat-set tool M2+M3 | €12 |
| Multimeter Fluke of gelijkwaardig | €30 |
| Oscilloscoop USB 50MHz | €35 |
| Precisie schroevendraaier set | €15 |
| Anti-statische mat + armband | €13 |
| **Subtotaal** | **€185** | |

---

## 12. FILAMENT — €485

| Materiaal | Hoeveelheid | Prijs | Gebruik | Vacuum |
|---|---|---|---|---|
| PEEK-CF (Kimya of 3DXTech) | 8 × 500g | €55/rol | Alles structureel | ✅ TML <0.1% |
| PA12-CF | 2 × 500g | €45/rol | Koppelings-neus · glijdende vlakken | ✅ |
| PEEK naturel (testprint) | 1 × 500g | €55 | Maatcontrole vóór CF print | ✅ |
| **Subtotaal** | | **€595** | | |

---

## 13. 3D PRINTER
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

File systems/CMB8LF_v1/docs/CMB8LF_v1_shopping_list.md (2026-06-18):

# CMB8LF-S1 — Boodschappenlijst
## Gefaseerd per Bouwmaand
**CC0 · Chrystal Moon Base · 2026**

Zie `BOM_v6.md` voor volledige specificaties en prijzen.

---

## Maand 1 — Gereedschap + Compute

**Gereedschap:**
- Soldeerbout 65W (Hakko FX-888D)
- Soldeertim 60/40 0.6mm
- Digitale schuifmaat 0.01mm
- Heat-set tool M2+M3
- Multimeter Fluke of gelijkwaardig
- Oscilloscoop USB 50MHz
- IPA 99% reiniging

**Compute:**
- Raspberry Pi 5 8GB ×1
- Raspberry Pi Pico W ×2
- RP2350 module ×3 (begin klein)
- MicroSD 64GB ×1
- Canable USB-CAN adapter ×1

**Printer:**
Zie PRINT_SETTINGS.md — primaire printer CreatBot PEEK-300; DIY-alternatieven (Voron/Intamsys) op basis van budget

---
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

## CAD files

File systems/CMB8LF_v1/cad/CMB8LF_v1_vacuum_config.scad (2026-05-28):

// ============================================================
// CMB8LF v1 — vacuum_config.scad v2
// Centrale dimensieconfiguratie — BEREKENDE WAARDEN
// Include in alle andere bestanden
// CC0 · Chrystal Moon Base · 2026
// ============================================================
// MAATCASCADE: elektronica → bot → aerogel → schild → grijper
// Alle maten wetenschappelijk berekend uit datasheets
// ============================================================

// ── MATERIAALWANDEN ──────────────────────────────────────────
PEEK_WALL      = 3.0;   // mm PEEK-CF wand (structureel minimum)
AEROGEL_THICK  = 10.0;  // mm aerogel isolatie (thermisch berekend)
                         // Peary -50°C buiten → -10..+40°C binnen
                         // λ=0.015 W/m·K · intern ~5W warmtebron
SHIELD_WALL    = 3.0;   // mm buitenschild PEEK-CF

// ── SEGMENT BINNENMATEN (elektronica bepaalt dit) ────────────
// Coxa: GM5208 ⌀50mm + moteus 46mm + 6× 16340 batterij 32×48mm
COXA_IN_W      = 54.0;  // mm breedte binnenkern
COXA_IN_D      = 72.0;  // mm diepte binnenkern

// Femur: GM4108H ⌀40.8mm + moteus 46mm + batterij
FEMUR_IN_W     = 52.0;
FEMUR_IN_D     = 70.0;

// Tibia: GM3506 ⌀35mm + moteus 46mm (dominant) + batterij
TIBIA_IN_W     = 50.0;
TIBIA_IN_D     = 68.0;

// ── SEGMENT BUITENMATEN (+ 2× PEEK_WALL) ────────────────────
COXA_OUT_W     = COXA_IN_W  + 2 * PEEK_WALL;  // 60mm
COXA_OUT_D     = COXA_IN_D  + 2 * PEEK_WALL;  // 78mm
FEMUR_OUT_W    = FEMUR_IN_W + 2 * PEEK_WALL;  // 58mm
FEMUR_OUT_D    = FEMUR_IN_D + 2 * PEEK_WALL;  // 76mm
TIBIA_OUT_W    = TIBIA_IN_W + 2 * PEEK_WALL;  // 56mm
TIBIA_OUT_D    = TIBIA_IN_D + 2 * PEEK_WALL;  // 74mm

// ── SEGMENTLENGTEN ────────────────────────────────────────────
COXA_L         = 85.0;
FEMUR_L        = 145.0;
TIBIA_L        = 105.0;

// ── SCHILDMATEN (bot + aerogel + schildwand) ─────────────────
// Aerogel zit OM het bot — gaat NIET mee met schild
// Schild klapt eromheen — gripuitsparingen op schild buiten
COXA_SH_W      = COXA_OUT_W  + 2 * AEROGEL_THICK + 2 * SHIELD_WALL;  // 86mm
COXA_SH_D      = COXA_OUT_D  + 2 * AEROGEL_THICK + 2 * SHIELD_WALL;  // 104mm
FEMUR_SH_W     = FEMUR_OUT_W + 2 * AEROGEL_THICK + 2 * SHIELD_WALL;  // 84mm
FEMUR_SH_D     = FEMUR_OUT_D + 2 * AEROGEL_THICK + 2 * SHIELD_WALL;  // 102mm
TIBIA_SH_W     = TIBIA_OUT_W + 2 * AEROGEL_THICK + 2 * SHIELD_WALL;  // 82mm
TIBIA_SH_D     = TIBIA_OUT_D + 2 * AEROGEL_THICK + 2 * SHIELD_WALL;  // 100mm

// ── GRIPUITSPARINGEN (op schild buitenkant) ──────────────────
// 4 stuks · 90° verdeling · trapezium vorm (zelfcentrerend)
GRIP_N         = 4;     // aantal uitsparingen
GRIP_DEPTH     = 8.0;   // mm diep (vinger grijpt zeker)
GRIP_W_OUTER   = 16.0;  // mm breed aan buitenkant
GRIP_W_INNER   = 12.0;  // mm breed binnenin (trapezium = zelfcentrerend)
GRIP_H         = 20.0;  // mm hoog langs het bot
GRIP_POS_FRAC  = 0.35;  // positie: 35% vanaf uiteinde

// ── GRIJPER MATEN (door schildmaat bepaald) ──────────────────
// Grootste object = coxa schild = 86 × 104mm
GRIP_SPAN      = 110.0; // mm box grip spanwijdte (104 + 2× 3mm speling)
FINGER_L       = 55.0;  // mm vingerlengte
FINGER_W       = 12.0;  // mm vingerbreedte
PALM_W         = 70.0;  // mm palmbreedte
PALM_D         = 55.0;  // mm palmdiepte
PALM_H         = 42.0;  // mm palmhoogte

// ── KOPPELING ─────────────────────────────────────────────────
COUPLING_DIA   = 55.0;
COUPLING_H     = 28.0;
GUIDE_ANGLE    = 30;
POGO_RING_DIA  = 35.0;
POGO_N         = 5;

// ── BODY ──────────────────────────────────────────────────────
BODY_L         = 400.0;
BODY_W_MAX     = 300.0;
BODY_W_FRONT   = 200.0;
BODY_W_REAR    = 180.0;
BODY_H         = 85.0;

// ── HOOFD ─────────────────────────────────────────────────────
HEAD_W         = 90.0;
HEAD_D         = 70.0;
HEAD_H         = 60.0;

// ── MOTOR AFMETINGEN (uit datasheets) ────────────────────────
MOTOR_COXA_DIA  = 50.0;   // GM5208-150T
MOTOR_COXA_H    = 20.0;
MOTOR_FEMUR_DIA = 40.8;   // GM4108H-120T
MOTOR_FEMUR_H   = 26.0;
MOTOR_TIBIA_DIA = 35.0;   // GM3506-2
MOTOR_TIBIA_H   = 20.0;

// ── MOTEUS r4.11 (uit datasheet) ─────────────────────────────
MOTEUS_W        = 46.0;
MOTEUS_D        = 46.0;
MOTEUS_H        = 14.0;

// ── LASER PALM ────────────────────────────────────────────────
LASER_BORE_DIA  = 5.7;
LASER_SPACING   = 5.0;

// ── PRINT RESOLUTIE ───────────────────────────────────────────
$fn = 64;   // productie
// $fn = 16; // snelle preview

// ── HULPFUNCTIES ─────────────────────────────────────────────
module rounded_box(w, d, h, r=3) {
    hull() {
        for (x = [-w/2+r, w/2-r])
        for (y = [-d/2+r, d/2-r])
        translate([x, y, 0])
        cylinder(r=r, h=h);
    }
}

module hollow_box(w, d, h, wall, r=3) {
    difference() {
        rounded_box(w, d, h, r);
        translate([0, 0, wall])
        rounded_box(w-2*wall, d-2*wall, h, max(1, r-wall));
    }
}

module heat_set(dia=3.2, depth=6) {
    cylinder(d=dia, h=depth);
}

// Trapezium gripuitsparing (zelfcentrerend)
module grip_recess() {
    hull() {
        translate([0, 0, 0])
        cube([GRIP_W_OUTER, GRIP_DEPTH, GRIP_H], center=true);
        translate([0, GRIP_DEPTH * 0.4, 0])
        cube([GRIP_W_INNER, 0.1, GRIP_H * 0.8], center=true);
    }
}

// Aerogel mantel om het bot
module aerogel_wrap(out_w, out_d, length) {
    color("Wheat", 0.6)
    difference() {
        rounded_box(out_w + 2*AEROGEL_THICK,
                    out_d + 2*AEROGEL_THICK,
                    length, r=5);
        rounded_box(out_w + 1, out_d + 1, length + 2, r=3);
    }
}

echo("vacuum_config.scad v2 geladen — BEREKENDE MATEN");
echo(str("Coxa schild: ",  COXA_SH_W,  " × ", COXA_SH_D,  "mm"));
echo(str("Femur schild: ", FEMUR_SH_W, " × ", FEMUR_SH_D, "mm"));
echo(str("Tibia schild: ", TIBIA_SH_W, " × ", TIBIA_SH_D, "mm"));
echo(str("Grijper span: ", GRIP_SPAN, "mm"));
echo(str("Aerogel: ",      AEROGEL_THICK, "mm"));

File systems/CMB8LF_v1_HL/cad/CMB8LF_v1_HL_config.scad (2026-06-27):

// ============================================================
// CMB8LF v1 HL — CMB8LF_v1_HL_config.scad
// Head-Less variant config — OVERRIDES ONLY
// Includes the shared base config; adds body-integrated
// sensor positions. Does NOT redefine shared dimensions.
// CC0 · Chrystal Moon Base · 2026
// ============================================================

// Pull in ALL shared dimensions (body, legs, couplings, motors).
// Only NEW or CHANGED values are defined below.
include <../../CMB8LF_v1/cad/CMB8LF_v1_vacuum_config.scad>

// ── HEAD-LESS: no head module ───────────────────────────────
// HEAD_W/HEAD_D/HEAD_H from the base are now UNUSED (no head).
// The front head coupling is blanked (see body_chassis HL).
HEADLESS              = true;

// ── WORK-SENSING WINDOW (front lobe, forward/down) ──────────
// Position is on the front lobe of the spider body.
WORKWIN_X            = BODY_L * 0.40;   // forward, on the front lobe
WORKWIN_Z           = BODY_H * 0.35;    // lower third (looks down at palms)
WORKWIN_W           = 46.0;             // window aperture width  (mm)
WORKWIN_H           = 30.0;             // window aperture height (mm)
WORKWIN_TILT        = 25;               // deg oblique (off-axis from laser)
WORKWIN_RECESS      = 12.0;             // mm set-back recess depth
WORKWIN_GLASS_T     = 2.0;              // mm sacrificial window thickness

// Thermal (FLIR Lepton 3.5) and visual (Pi Cam 3 NoIR) share the
// recess, side by side, behind the sacrificial window.
THERMAL_DX          = 14.0;             // offset within window
VISUAL_DX           = -12.0;

// ── ILLUMINATION RING (around work window) ──────────────────
IRLED_COUNT         = 6;
IRLED_RING_R        = 26.0;             // mm radius around window
SPOT_DIA            = 18.0;             // 10W spotlight aperture

// ── 360 AWARENESS ───────────────────────────────────────────
LIDAR_RISER_X       = 0;                // body top centre
LIDAR_RISER_Y       = 0;
LIDAR_RISER_H       = 18.0;             // short fixed riser
LIDAR_DIA           = 70.0;             // RPLIDAR A1M8 body

TOF_Z               = BODY_H * 0.45;    // side ToF height
TOF_DIA             = 8.0;

// ── OVERRIDE SURROUND CAMERAS ───────────────────────────────
// Wide-angle fixed cameras around the body for engineer override.
// Azimuths (deg) measured from front (0 = forward).
SURROUND_CAM_AZ     = [0, 90, 180, 270];
SURROUND_CAM_Z      = BODY_H * 0.6;
SURROUND_CAM_DIA    = 16.0;

// ── FSO COMMS PORT ──────────────────────────────────────────
FSO_X               = BODY_L * 0.30;
FSO_DIA             = 12.0;

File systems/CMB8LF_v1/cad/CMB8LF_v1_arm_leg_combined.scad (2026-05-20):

// ============================================================
// CMB8LF v1 — ARM/LEG COMBINED MODULE
// Leg 1 + Leg 2 · Dual function: walking foot OR robot arm
// Gripper end-effector · Quick release · Laser indicators
// ============================================================
// RENDER MODES:
//   MODE = "arm"      → gripper end-effector actief
//   MODE = "leg"      → standaard voet actief
//   MODE = "assembly" → volledig been + end-effector
//   MODE = "test"     → gripper + QR testprint isolatie
// ============================================================

$fn = 24; // 24 test · 80 finale print

MODE = "assembly";

// ── SERVO SPECS ───────────────────────────────────────────────
ds3240_w       = 40.5; ds3240_d = 20.5; ds3240_h = 40.0;
ds3240_shaft   = 33.0; ds3240_shaft_d = 5.9; ds3240_mount = 28.0;

ds3225_w       = 40.5; ds3225_d = 20.5; ds3225_h = 38.0;
ds3225_shaft   = 32.0; ds3225_shaft_d = 5.9; ds3225_mount = 28.0;

ds3218_w       = 40.5; ds3218_d = 20.5; ds3218_h = 36.0;
ds3218_shaft   = 30.0; ds3218_shaft_d = 5.9; ds3218_mount = 28.0;

// ── LAGER: F688-2RS 8×16×5mm ─────────────────────────────────
brg_od = 16.0; brg_id = 8.0; brg_h = 5.0; brg_tol = 0.1;

// ── BEEN AFMETINGEN ───────────────────────────────────────────
femur_len  = 134.0; // +12mm tov standaard been voor arm bereik
tibia_len  = 95.0;
hip_offset = 18.0;

// ── PRINT PARAMETERS ─────────────────────────────────────────
wall       = 5.0;
armor_wall = 2.5;
thermal_gap = 1.2;
tol_fit    = 0.2;
tol_snap   = 0.15; // PETG-CF · 0.15 per kant
heatset_d  = 3.2;
heatset_dep = 6.0;
m3_clear   = 3.4;
rib_w      = 1.5;
cool_slot_w = 3.0;
cool_slot_d = 2.5;
vent_w     = 1.8;
cable_ch_w = 8.0;
cable_ch_h = 6.0;

// ── GRIPPER SPECS ─────────────────────────────────────────────
grip_servo_w   = 40.5; // DS3225 of MG996R
grip_servo_d   = 20.5;
grip_servo_h   = 38.0;
grip_jaw_len   = 45.0; // kaaklengte
grip_jaw_w     = 18.0; // kaakbreedte
grip_jaw_h     = 12.0; // kaakhoogte
grip_open_ang  = 45;   // max openingshoek graden
grip_finger_t  = 4.0;  // vingerwand dikte

// ── QUICK RELEASE SPECS ───────────────────────────────────────
qr_pin_d    = 3.2;
qr_spring_w = 2.5;  // v1.1 fix: was 1.5mm
qr_depth    = 14.0; // iets dieper dan standaard been
qr_catch_d  = 4.5;
qr_body_d   = 22.0; // body diameter QR connector
qr_body_h   = 18.0; // body hoogte QR connector
qr_pole     = 3;    // aantal vergrendelpennen (120° spacing)

// ── LASER SPECS ───────────────────────────────────────────────
laser_d     = 6.2;  // 6mm module + 0.2 speling
laser_d_armor = 7.0; // venster in armor
laser_spacing = ds3218_d / 3;

// ============================================================
// HULP-MODULES
// ============================================================

module m3_heatset(depth = heatset_dep) {
    cylinder(d = heatset_d, h = depth + 0.1);
}

module bearing_pocket(tol = brg_tol) {
    cylinder(d = brg_od + tol*2, h = brg_h + tol);
}

module servo_volume(w, d, h, clearance = tol_fit) {
    translate([-w/2-clearance, -d/2-clearance, -clearance])
        cube([w+clearance*2, d+clearance*2, h+clearance*2]);
    translate([-cable_ch_w/2, -d/2-clearance, -clearance-cable_ch_h])
        cube([cable_ch_w, d+clearance*2, cable_ch_h+1]);
}

module cooling_channels_side(servo_h, servo_d, count=4) {
    spacing = (servo_h - wall) / (count + 1);
    for(i = [1:count])
        translate([-cool_slot_w/2, -servo_d/2-cool_slot_d, i*spacing])
            cube([cool_slot_w, cool_slot_d+0.1, cool_slot_w]);
}

module thermal_pad_seat(w, d, depth=0.8) {
    translate([-w/2, -d/2, -0.1])
        cube([w, d, depth+0.1]);
}

module ribs(length, height, count=5) {
    spacing = length / (count+1);
    for(i = [1:count])
        translate([i*spacing - length/2, 0, 0])
            cube([rib_w, wall+2, height], center=true);
}

module dovetail_male(h=8) {
    linear_extrude(h)
        polygon(points=[[-2,0],[-4,6],[4,6],[2,0]]);
}

module dovetail_female(h=8) {
    linear_extrude(h+0.2)
        polygon(points=[
            [-2-tol_snap,-0.1],[-4-tol_snap,6+tol_snap],
            [4+tol_snap,6+tol_snap],[2+tol_snap,-0.1]
        ]);
}

// ── Quick release met 2.5mm veer + 45° fillet ────────────────
module quick_release_slot() {
    translate([-qr_pin_d/2-tol_snap, 0, 0])
        cube([qr_pin_d+tol_snap*2, qr_depth, qr_pin_d+tol_snap*2]);
    translate([-qr_spring_w/2, 0, -qr_pin_d])
        cube([qr_spring_w, qr_depth, qr_pin_d*2]);
    // 45° fillet voor sterkte
    translate([-qr_spring_w/2, 0, -qr_pin_d])
        rotate([0, 45, 0])
            cube([qr_spring_w*0.7, qr_depth, qr_spring_w*0.7]);
    translate([0, qr_depth-qr_catch_d/2, 0])
        sphere(d=qr_catch_d+tol_snap);
}

// ── Laser module mount ────────────────────────────────────────
module laser_mount(armor=false) {
    d = armor ? laser_d_armor : laser_d;
    rotate([0, 90, 0])
        cylinder(d=d, h=wall*2+1, center=true);
}

// ============================================================
// QUICK RELEASE BODY CONNECTOR
// ── 3-polige vergrendeling, geen gereedschap ─────────────────
// Printen in PETG-CF · past op heup van ALLE benen
// ============================================================

module qr_connector_body() {
    // Mannelijk deel — zit aan het been
    difference() {
        union() {
            // Hoofdcilinder
            cylinder(d=qr_body_d, h=qr_body_h);
            // Flens voor positiebepaling
            translate([0, 0, qr_body_h-2])
                cylinder(d=qr_body_d+4, h=2);
        }
        // As doorvoer
        cylinder(d=brg_id+tol_fit*2, h=qr_body_h+1, center=false);
        // 3 vergrendelpennen op 120°
        for(i=[0:qr_pole-1])
            rotate([0, 0, i*(360/qr_pole)])
                translate([qr_body_d/2-2, 0, qr_body_h/2])
                    rotate([90, 0, 0])
                        quick_release_slot();
        // Kabelgoot door connector
        translate([-cable_ch_w/2, -cable_ch_w/2, -0.1])
            cube([cable_ch_w, cable_ch_w, qr_body_h+1]);
    }
}

module qr_connector_socket() {
    // Vrouwelijk deel — zit op de body/chassis
    difference() {
        cylinder(d=qr_body_d+wall*2, h=qr_body_h+wall);
        // Uitsparing voor mannelijk deel
        translate([0, 0, wall])
            cylinder(d=qr_body_d+tol_snap*2, h=qr_body_h+1);
        // As doorvoer
        cylinder(d=brg_id+tol_fit*2, h=qr_body_h+wall+1);
        // Lager pocket boven
        translate([0, 0, wall])
            bearing_pocket();
        // Vangst gaten voor 3 pennen
        for(i=[0:qr_pole-1])
            rotate([0, 0, i*(360/qr_pole)+60])
                translate([qr_body_d/2+tol_snap, 0,
                           qr_body_h/2+wall])
                    rotate([90, 0, 0])
                        cylinder(d=qr_pin_d+tol_snap*2, h=8,
                                 center=true);
        // Kabelgoot
        translate([-cable_ch_w/2, -cable_ch_w/2, -0.1])
            cube([cable_ch_w, cable_ch_w, qr_body_h+wall+1]);
    }
}

// ============================================================
// GRIPPER END-EFFECTOR
// ── DS3225/MG996R servo · twee kaken · veerbelast open ───────
// ============================================================

module gripper_jaw(side=1) {
    // Één kaak — gespiegeld voor linker/rechter
    mirror([0, side<0?1:0, 0])
    difference() {
        union() {
            // Kak lichaam
            hull() {
                cube([grip_jaw_len, grip_jaw_w/2,
                      grip_jaw_h], center=false);
                translate([grip_jaw_len, 0, grip_jaw_h/2])
                    rotate([0, 90, 0])
                        cylinder(d=grip_jaw_h, h=2);
            }
            // Servo horn bevestiging
            translate([0, 0, grip_jaw_h/2])
                rotate([0, 90, 0])
                    cylinder(d=grip_jaw_h+4, h=grip_finger_t);
        }
        // Servo horn gat
        translate([grip_finger_t/2, 0, grip_jaw_h/2])
            rotate([0, 90, 0])
                cylinder(d=ds3225_shaft_d+tol_fit*2,
                         h=grip_finger_t+1, center=true);
        // Grip reliëf (binnenzijde kak)
        for(i=[0:3])
            translate([8+i*9, -0.1, grip_jaw_h/2])
                rotate([90, 0, 0])
                    cylinder(d=3, h=grip_jaw_w/2+1);
        // Gewichtsreductie
        translate([grip_jaw_len/2, grip_jaw_w/4,
                   grip_jaw_h/2])
            cube([grip_jaw_len-grip_finger_t*4,
                  grip_jaw_w/4, grip_jaw_h-grip_finger_t*2],
                 center=true);
    }
}
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

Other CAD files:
systems/CMB8LF_v1/cad/CMB8LF_v1_leg_complete.scad
systems/CMB8LF_v1/cad/CMB8LF_v1_ambient_lighting.scad
systems/CMB8LF_v1/cad/CMB8LF_v1_body_chassis.scad
systems/CMB8LF_v1/cad/CMB8LF_v1_coupling_interface.scad
systems/CMB8LF_v1/cad/CMB8LF_v1_head_module.scad
systems/CMB8LF_v1/cad/CMB8LF_v1_leg_gripper.scad
systems/CMB8LF_v1/cad/CMB8LF_v1_leg_standard.scad
systems/CMB8LF_v1/cad/CMB8LF_v1_palm_laser.scad
systems/CMB8LF_v1_HL/cad/CMB8LF_v1_HL_body_chassis.scad
systems/CMB8LF_v1_HL/cad/CMB8LF_v1_HL_sensor_mounts.scad

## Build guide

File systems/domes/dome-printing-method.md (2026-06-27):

# Dome Printing Method
## Chrystal Moon Base — Construction Concept

**Status:** Concept proposal — significant engineering development required  
**Licence:** CC0

---

## Overview

Domes are not assembled from pre-manufactured components. They are printed in place by CMB8LF-L1 robots from local materials, in a sequence that builds each layer outward from the center, starting with the innermost glass layer and ending with the outer sintered regolith shell.

The "inside-out" printing approach — starting from the inner glass surface and working outward — was chosen because the optical quality of the inner glass surface (which residents will see and which must be smooth and clear) is highest when it is printed first, before the mechanical disturbance of outer layer construction.

---

## Pre-Construction Requirements

Before any dome is printed, the following must be complete:

1. **Sintered regolith foundation ring** — a ring of sintered floor at the dome perimeter, to the exact diameter of the dome. This is the base on which the dome walls will be printed.

2. **Underground connections installed** — all power, data, water, gas, and access connections are routed through the floor and terminated at their connection points inside the dome footprint. All floor penetrations are sealed.

3. **Floor surface prepared** — the floor inside the dome footprint is sintered, levelled, and verified by the Watcher robot.

4. **Printing robots positioned** — sintering robots on the inside of the dome footprint and on the outside simultaneously.

---

## Printing Sequence

### Step 1 — Inner Glass Layer (Layer 5)
Robots on the inside of the foundation ring begin printing the inner glass layer. The M-Glass module supplies molten glass through a delivery system. Robots lay the glass in molten form, building the dome shell layer by layer from bottom to top.

As the glass is applied, high-temperature reinforcing fibre (material TBD — alumina or mineral fibre, not titanium or aluminium metal; see dome-layer-architecture.md) is laid continuously into the molten glass by a second robot arm, creating the reinforced composite as it cools.

The anti-decay coating is applied as a final step on the interior surface before the glass fully cools.

### Step 2 — Water Cavity Structure (Layer 3 outer surface + Layer 4 boundary)
The second glass layer (Layer 3) is printed outside and around Layer 5, with a defined gap between them for the water cavity. A sealing system at the base connects the two glass shells to form a sealed annular cavity.

The gold coating is applied to the exterior surface of Layer 3 before the next layer is applied. Applying it now ensures the gold layer is protected by the subsequent outer layers.

### Step 3 — Self-Sealing Gel Layer (Layer 2)
The self-sealing gel is applied to the exterior of Layer 3. The specific application method depends on the gel formulation selected — spray, extrusion, or injection into a pre-formed cavity are all possible.

### Step 4 — Outer Sintered-Regolith Shell (Layer 1)
Robots on the outside of the dome begin sintering the outer regolith shell. They work upward from the foundation ring, sintering layer by layer, using local regolith. The dome is built from the outside while the glass is already complete inside.

The outer shell is sintered thick enough for the required radiation shielding. Thickness varies with position — thicker at the top (maximum radiation exposure), potentially thinner on the sides where the underground tunnel connections are made.

### Step 5 — Water Fill
Once the dome is complete and structurally verified, the water cavity (Layer 4) is filled from the underground cistern supply through the floor connection. The fill is gradual — over days or weeks — to allow monitoring for leaks.

### Step 6 — Pressure Test
The dome is pressurised to the design habitat pressure using an automated system. Pressure is held for a defined period and monitored for any drop. Only after successful pressure testing is human access permitted.

---

## Key Engineering Questions

1. **Glass delivery system** — how is molten glass delivered from the M-Glass module to the printing robot at the dome construction site? What thermal management is required to keep glass molten during transport?
2. **Reinforcing-fibre placement precision** — how does the robot ensure continuous, uniform fibre distribution throughout the glass wall thickness during printing?
3. **Dome height without support** — as the dome grows taller, the unsintered upper sections must support their own weight until complete. What temporary support structure, if any, is required?
4. **Inner and outer coordination** — robots working on the inside and outside of the dome simultaneously must not interfere. What coordination protocol prevents collisions through the growing dome wall?
5. **Quality verification during printing** — how does the Watcher robot verify layer quality at intermediate steps, before subsequent layers are added and make inspection impossible?

---

## Sources & verification

The dome *printing sequence* (inside-out layer order, simultaneous inner/outer robots, fill-and-test) is this project's construction concept. The underlying feasibility — that lunar regolith can be sintered / 3D-printed in place into structural building elements — is established by space-agency research:

- **ESA regolith 3D-printing demonstrator.** ESA and Foster + Partners produced a **1.5-tonne building block** from lunar-soil simulant to demonstrate 3D-printed lunar construction; later work showed printing can work in vacuum (droplets held by capillary forces). ESA, *Building a lunar base with 3D printing* — https://www.esa.int/Enabling_Support/Space_Engineering_Technology/Building_a_lunar_base_with_3D_printing ; ESA ESTEC 3D-printed block — https://99estec-objects.esa.int/object-items/4
- **Solar sintering of regolith — binder-free.** ESA baked moondust in **0.1 mm layers at ~1000 °C** into bricks using only concentrated sunlight, no Earth binder — directly supporting CMB's laser/solar-sinter approach. ESA, *3D printing of a model building block for a lunar base outer shell* — https://www.esa.int/Enabling_Support/Space_Engineering_Technology/Shaping_the_Future/3D_printing_of_a_model_building_block_for_a_lunar_base_outer_shell
- **Sintering as an active research field.** Peer-reviewed reviews catalogue multiple regolith-sintering techniques (solar, microwave, laser, powder-bed fusion) and their processing parameters for ISRU construction. *Progress in Additive Manufacturing* (2023), *Regolith sintering and 3D printing for lunar construction: a review* — https://link.springer.com/content/pdf/10.1007/s40964-023-00537-1.pdf ; crater-covering dome concept, *Scientific Reports* (2025) — https://www.nature.com/articles/s41598-025-07901-x

> Note: ESA's demonstrators are **brick/block scale** with simulant; printing a full pressurised multi-layer dome with an optical-quality inner glass surface is far beyond current demonstration. The five Key Engineering Questions above are the real gaps and remain open.

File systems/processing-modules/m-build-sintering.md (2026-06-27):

# M-Build — The Build Line (Sintered Regolith Construction)

**Status:** Concept proposal with sourced technical grounding. Schematics are
*conceptual*, not engineering drawings — flagged as such.
**Licence:** CC0
**Role in the chain:** Stage 1 — comes **first**, before MRE and before any
purification. Turns raw regolith directly into structure (floors, walls, halls,
underground rooms, silos). Lowest purity requirement (none), highest urgency.
**Ground truth:** Peary is highland / anorthosite (`PEARY-MATERIALS-REFERENCE.md`).

---

## What it does

The build line fuses **raw local regolith** into solid structure using only heat (and
sometimes pressure) — no reagents, no imports. It builds the very halls and silos that
every later factory and store must sit inside. It is therefore the first thing the
robot fleet does on the surface, and it runs continuously (the rolling build front):
whatever is finished is used immediately.

---

## Input → Output

- **Input:** raw anorthosite regolith + concentrated energy (solar or laser).
- **Output:** load-bearing sintered/melted regolith — floors, walls, vault shells,
  road/landing surfaces, silo bodies, and the lining of excavated underground rooms.
- **By-property:** the product is a *material*, not a purified substance. Its measure
  is strength and density, not a purity %.

---

## The science (grounded)

**Sintering** bonds powder particles by thermal diffusion **without fully melting**,
in three stages: (1) inter-particle necks form, (2) necks grow and pores shrink,
(3) grain growth and densification to minimum porosity. **Melting** (laser/solar melt)
goes further — full liquefaction then re-solidification — and is reported to be about
**10× more energy-efficient than sintering for consolidation** of anorthosite-rich
regolith, at the cost of more thermal stress (cracking risk).

**Temperatures (anorthosite-rich, sourced):** sintering begins ~**1180 °C**, full melt
above ~**1360 °C** for an 80 % anorthosite / 20 % basalt south-pole simulant. Other
methods optimise lower: spark plasma sintering ~1000 °C; microwave ~995–1010 °C for
highland simulant; flash sintering 1050–1290 °C.

**Strength — far more than needed.** Reduced lunar gravity means most structures need
only ~**4 MPa** compressive strength. Sintered regolith vastly exceeds this:
- ~**85 MPa** at ~12 % porosity, ~**219 MPa** at ~1.4 % porosity (furnace).
- Microwave: ~37 MPa up to ~**309 MPa**; ~**142 MPa** for highland anorthosite.
- Spark plasma sintering: up to ~**566 MPa**.
- Laser melting (paving): ~17–20 MPa.

So strength is not the constraint — **porosity/airtightness is** (see below).

---

## The highland caveat (honest)

Microwave sintering couples through nanophase iron and high-permittivity minerals
(olivine, ilmenite). Highland anorthosite is **iron-poor**, so it couples *less* well
with microwaves — studies show lower density with higher anorthosite content. The
practical reading for Peary: **laser and concentrated-solar sintering/melting are the
better fit** than microwave, because they deposit heat directly rather than relying on
the regolith's (weak) microwave absorption.

---

## The engineering — energy delivery

- **Concentrated solar:** raw solar flux at the Moon is ~**1,361 W/m²** (varies ~1,321–1,413 over the year); Fresnel
  lenses or parabolic mirrors can intensify it up to ~10,000×, giving ~**1–10 MW/m²** —
  well above the ~100–200 kW/m² at which sintering has been demonstrated (900–1200 °C).
  A solar 3D-printed brick has been made from simulant. Limitation: sunlight varies, so
  steady output benefits from buffering or a controlled (e.g. xenon-lamp) source.
- **Laser (CO₂ / fibre):** steady, controllable, and ~10× more efficient for melting.
  Fits the CMB robot's laser palm. Best for precise floor/wall layers.

### Conceptual schematic — robot laser-sintering a floor layer

```
        CMB8LF robot arm
              │
        ┌─────┴─────┐
        │  laser /  │   <- 808 nm sinter / 976 nm anneal (per S1 design)
        │  optics   │      or concentrated-solar spot
        └─────┬─────┘
              ▼  focused beam (~MW/m² spot)
   ░░░░░░░░░█████░░░░░░░░░   <- melt/sinter pool tracks across the bed
   ▓▓▓▓▓▓▓▓▓▓▓▓▓▓▓▓▓▓▓▓▓▓▓   <- newly fused layer (load-bearing)
   ▓▓▓▓▓▓▓▓▓▓▓▓▓▓▓▓▓▓▓▓▓▓▓   <- previous fused layers
   ·························   <- raw regolith bed below
        (layer-by-layer, like 3D printing in stone)
```
*Conceptual only — spot size, scan speed and layer thickness are open parameters.*

---

## Lunar-specific factors

- **Vacuum helps:** sintering/melting in low vacuum (~10⁻³ mbar) has been demonstrated;
  no oxidation, no trapped air.
- **1/6 gravity:** favourable — low structural loads (hence the ~4 MPa requirement).
- **Dust & thermal cycling:** abrasive dust and the day/night swing stress equipment;
  notably, some sintered samples *gained* strength after thermal cycling (pore closure).
- **No binder needed:** unlike binder-jetting, thermal fusion needs no imported glue.

---

## The airtightness problem (links to later stages)

Sintered regolith is **porous**. It is strong enough to hold up a structure, but not
inherently airtight. So the build line gives the **rough shell**; making rooms hold
pressure needs a **glass/silica coating** from the M-Glass / silica stream. Sequence:
rough build first → seal once the glass plant runs. Rough construction leads; sealing
follows.

---

## Maturity (honest)

Sintering/melting of regolith simulant is relatively mature in the lab (microwave,
laser, SPS, solar all demonstrated; solar brick made). What is unproven is **large-area,
autonomous, layer-by-layer construction on the surface** by robots — that is exactly
what Gate 1→3 of the growth model must demonstrate.

---

## Open questions

1. Laser vs concentrated-solar as the primary method at Peary (energy budget vs control)?
2. Optimal layer thickness, scan speed and overlap for crack-free large slabs?
3. How thick a sealing glass layer is needed, and applied in the same pass or later?
4. Crack control on melt (the 10×-efficiency route) for anorthosite (~1550 °C melt)?

---

## References (verify and extend)

- ScienceDirect 2025 — *Sintering of Lunar regolith: A review* (three-stage model).
- ScienceDirect 2025 — *Laser Melting vs. Laser Sintering, Schrödinger south-pole
  simulant*: sintering ~1180 °C, melt >1360 °C, melt ~10× more efficient.
- ScienceDirect 2025 (Construction & Building Materials) — microwave sintering of
  highland (HUST-2) anorthosite simulant: ~142 MPa; anorthosite couples less well.
- ScienceDirect 2023 — spark plasma sintering HUST-1: up to 566 MPa at ~1000 °C.
- arXiv 2506.06392 — https://arxiv.org/abs/2506.06392 — solar flux 1,360 W/m², 10,000× concentration → 1–10 MW/m².
- ScienceDirect 2025 review — microwave 309 MPa; lunar structures need only ~4 MPa.
- Indyk & Benaroya 2017 — 85 MPa / 219 MPa by porosity.

*Strength values are simulant lab results; lunar anorthosite performance is unproven.
This is a proposal, not a settled design.*

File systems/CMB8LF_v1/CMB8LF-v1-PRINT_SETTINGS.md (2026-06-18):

# CMB8LF-S1 — Print Settings & Tolerances

**Printer:** QIDI Tech Plus4 (305×305×280mm, 65°C chamber, 370°C hotend)  
**Slicer:** OrcaSlicer / QIDI Print  
**Last updated:** 2026  
**Licence:** CC0

---

## Critical: Before You Print Anything

Run these calibrations in order on fresh filament. Do not skip.  
Wrong calibration on CF filaments = parts that don't fit. No exceptions.

### 1. Flow Rate Calibration (per filament)
CF filaments flow differently than standard plastics.

1. Print a flow rate calibration cube in OrcaSlicer
2. Measure wall thickness with calliper
3. Adjust flow until walls hit target exactly
4. Save profile per filament spool — do not mix profiles

> ⚠️ 1% too high = parts printed oversize = bayonet and dovetail joints won't close

### 2. X-Y Hole Compensation
Holes always shrink inward on FDM prints. Without compensation:
- M2/M3 bolts will not pass through
- F688-2RS bearings (8mm shaft) will not seat
- Heat-set insert holes will be too tight to start the insert

**Setting in OrcaSlicer:** `Filament Settings → Advanced → X-Y Hole Compensation`

| Material | Compensation |
|---|---|
| PETG-CF | +0.10 mm to +0.15 mm |
| PA12-CF | +0.10 mm to +0.15 mm |
| TPU 95A | +0.00 mm (flexible, self-adjusts) |
| PLA+ | +0.10 mm (test prints only) |

> Start at +0.10mm. Print a bearing test hole (Ø8.0mm). If F688-2RS drops in cleanly with light press: correct. If tight: go to +0.15mm.

### 3. First Layer Calibration (Z-offset)
Run live Z-offset on every new build plate session. CF filaments are less forgiving than standard PETG on adhesion. PEI plate, no glue needed.

---

## Material Profiles

### PETG-CF — Chassis, frame, panels, electronics tray

| Parameter | Value |
|---|---|
| Nozzle | Hardened steel **0.6mm** |
| Nozzle temp | 250–260°C |
| Bed temp | 85°C |
| Chamber temp | 40–50°C |
| Print speed | 50 mm/s (perimeters), 80 mm/s (infill) |
| Layer height | 0.2mm |
| Walls | 4 perimeters |
| Infill | 40% gyroid |
| Cooling | Moderate (30–50% fan) |
| Supports | Tree supports, on build plate only |

> Use 0.6mm nozzle — not 0.4mm. Carbon fibre micro-particles clog 0.4mm nozzles quickly. 0.6mm also produces thicker walls = significantly stronger chassis.

### PA12-CF (Nylon Carbon) — Bayonet sockets, dovetail joints, bearing housings

| Parameter | Value |
|---|---|
| Nozzle | Hardened steel **0.6mm** |
| Nozzle temp | 270–280°C |
| Bed temp | 90°C |
| Chamber temp | **55–60°C** (active heating required) |
| Print speed | 40 mm/s (perimeters), 60 mm/s (infill) |
| Layer height | 0.2mm |
| Walls | 5 perimeters |
| Infill | 50% gyroid |
| Cooling | Minimal (0–15% fan) |
| Dry filament | **Yes — 8h at 70°C before printing** |
| Post-print | **Leave in closed chamber 30 min before opening** |

> The 30-minute closed-chamber cooldown is mandatory. Opening early causes internal stress in bayonet sockets and dovetail joints — parts will warp or crack under load.

> Dry PA12-CF before every session. Nylon absorbs moisture fast. Wet filament = weak layer adhesion = joints that fail under servo torque.

### TPU 95A — Snowshoe feet, vibration damping layers

| Parameter | Value |
|---|---|
| Nozzle | Hardened steel 0.4mm or 0.6mm |
| Nozzle temp | 225–235°C |
| Bed temp | 45°C |
| Chamber temp | Off / 30°C max |
| Print speed | 25 mm/s (slow — TPU strings at speed) |
| Layer height | 0.25mm |
| Walls | 3 perimeters |
| Infill | 20% gyroid |
| Retraction | Minimal or off |
| Cooling | High (80–100% fan) |

### PLA+ — Test prints only

| Parameter | Value |
|---|---|
| Nozzle | Any 0.4mm |
| Nozzle temp | 215°C |
| Bed temp | 60°C |
| Chamber temp | Off |
| Print speed | 60 mm/s |
| Layer height | 0.2mm |
| Walls | 3 perimeters |
| Infill | 20% gyroid |

> PLA+ is for fit testing only. Never install PLA+ parts in the final robot.

---

## Design Tolerances

Apply these in CAD before exporting to slicer. Non-negotiable.

### Sliding / Moving Interfaces (bayonet, dovetail, panel clips)

| Interface type | Clearance per side |
|---|---|
| Bayonet lock (leg socket) | **0.15–0.20mm** |
| Dovetail / chassis segment | **0.15–0.20mm** |
| Panel clip (shield panels) | **0.10–0.15mm** |
| Sliding rail | **0.20mm** |

> Start at 0.15mm. Print one test pair. If it locks smoothly with light force and releases cleanly with the wip tool: correct. Tighter = stuck. Looser = wobbles under servo load.

### Press-fit / Seated Interfaces

| Part | Design size | Note |
|---|---|---|
| F688-2RS bearing seat (Ø16mm OD) | **Ø15.85mm** | Light press fit |
| M3 bolt clearance hole | **Ø3.3mm** (before hole comp) | Passes freely |
| M2 bolt clearance hole | **Ø2.2mm** (before hole comp) | Passes freely |
| M3 heat-set insert hole | **OD_insert − 0.5mm** | Melts in snug |
| M2 heat-set insert hole | **OD_insert − 0.5mm** | Melts in snug |

> Heat-set insert holes: measure the outer diameter of your specific insert brand first. Then subtract 0.5mm. This gives the printed hole diameter. The plastic melts snugly around the insert and will not pull out under servo load.

### Sensor Cutouts

| Sensor | Cutout size | Note |
|---|---|---|
| RPLIDAR A1M8 | Ø76mm circle | Rotate scan window clear of frame |
| Pi Camera Module 3 | 25×24mm rectangle | Add 0.3mm clearance |
| VL53L1X | 5×2.5mm window | Flush with outer panel surface |

---

## Print Order — CMB8LF-S1

Print in this order. Each step validates the previous.

| Step | Part | Material | Purpose |
|---|---|---|---|
| 1 | Bearing test block (F688-2RS) | PETG-CF | Validate hole comp setting |
| 2 | M3 bolt test plate | PETG-CF | Validate clearance holes |
| 3 | Bayonet socket + poot pin (test pair) | PA12-CF | Validate 0.15mm tolerance |
| 4 | Dovetail pair (chassis test segment) | PETG-CF | Validate 0.15mm tolerance |
| 5 | Snowshoe foot ×1 | TPU 95A | Validate TPU profile |
| 6 | Snoeuwschoen voet final ×16 | TPU 95A | Full set |
| 7 | Chassis segment A (left half) | PETG-CF | First structural part |
| 8 | Chassis segment B (right half) | PETG-CF | Mate with A, check fit |
| 9 | Leg set ×8 (coxa, femur, tibia) | PETG-CF + PA12-CF | Per robot |
| 10 | Shield panels | PETG-CF | Last — outer skin |

> Never skip steps 1–5. Getting calibration wrong on step 1 wastes filament and time on every part that follows.

---

## Heat-Set Insert Installation

1. Heat soldering iron to **200–220°C** (lower than printing temp)
2. Place insert on hole opening — do not press yet
3. Touch iron tip gently to top of insert
4. Apply **slow, steady downward pressure** — let heat do the work
5. Stop when insert is **0.2–0.3mm below surface** (flush or just below)
6. Remove iron, hold insert still for **10 seconds** while plastic re-solidifies
7. Do not stress the insert for **2 minutes**

> Too fast = crooked insert = bolt goes in at an angle = joint fails.  
> Too hot = melted plastic floods the thread = useless.

---

*CC0 — Chrystal Moon Base 2026*  
*Calibration values validated for QIDI Tech Plus4 + OrcaSlicer*  
*Credit: slicer settings and tolerance methodology contributed by Gemini*

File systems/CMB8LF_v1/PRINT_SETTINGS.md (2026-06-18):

# CMB8LF-S1 — Print Instellingen v6
## PEEK-CF · CreatBot PEEK-300 (primary) · Voron 2.4 / Intamsys FUNMAT HT (DIY alternatives)
**CC0 · Chrystal Moon Base · 2026**

> **Primary printer: CreatBot PEEK-300.** The settings below are starting points. Calibration values must be **re-validated on the CreatBot PEEK-300** before relied upon — earlier QIDI/Voron-specific calibration has been removed. DIY contributors using a Voron 2.4 or Intamsys FUNMAT HT should re-tune for their own machine.

---

## ⚠ VEILIGHEID EERST

PEEK dampen zijn schadelijk bij langdurige blootstelling.
- Zorg voor goede ventilatie (afzuiging of buiten)
- Verlaat ruimte niet onbeheerd tijdens PEEK print
- Nozzle 400°C+ = brandgevaar — brandblussers aanwezig

---

## Printer Vereisten

| Parameter | Minimum | Aanbevolen |
|---|---|---|
| Hotend temperatuur | 380°C | 400-420°C |
| Bed temperatuur | 100°C | 110°C |
| Chamber temperatuur | 45°C | 80-100°C |
| Hotend type | All-metal | Phaetus Rapido HF 2 UHF |
| Nozzle | Hardstaal 0.4mm | Hardstaal 0.4mm |
| Firmware | Klipper aanbevolen | Klipper + Rapido macro's |

---

## Materiaal

**Primair: PEEK-CF (carbon fiber gevuld)**
- Merk: Kimya PEEK-CF of 3DXTech CarbonX PEEK+CF
- TML: < 0.1% (vacuüm gecertificeerd)
- Diameter: 1.75mm
- Bewaar in droogkast (< 20% RV) na openen

**Alternatief voor niet-kritische onderdelen:**
- PA12-CF voor scharnierende onderdelen
- PEEK naturel voor eerste testprints (goedkoper)

---

## Slicer Instellingen

| Parameter | Structureel (botten) | Detail (koppelingen) |
|---|---|---|
| Laagdikte | 0.20mm | 0.15mm |
| Infill % | 40% | 60% |
| Infill type | Gyroid | Gyroid |
| Wanden | 4 | 5 |
| Top/bottom lagen | 5 | 6 |
| Print snelheid | 35mm/s | 25mm/s |
| Ventilator | UIT | UIT |
| Pressure advance | ~0.030 | ~0.025 |

---

## Print Volgorde (per segment, aanbevolen)

1. PEEK naturel testprint (dimensiecontrole)
2. Maatcorrectie: PEEK krimpt ~1.2% — schaal ×1.012 in CAD
3. PEEK-CF productie print
4. Minimaal 2 uur afkoelen in gesloten printer
5. Verwijder ALLEEN als onderdeel < 40°C is
6. 48u stabilisatie voor vacuümtest

---

## Adhesie

- PEI bouwplaat + Magigoo PC
- Bed 110°C voor plaatsen onderdeel
- Eerste laag 0.25mm (iets dikker voor adhesie)
- Rand: 5mm brim voor grote vlakke onderdelen

---

## Probleemoplossing

| Probleem | Oorzaak | Oplossing |
|---|---|---|
| Slechte adhesie | Bed te koud / vuil | 110°C + Magigoo PC |
| Laagscheiding | Chamber te koud | Minimaal 55°C chamber |
| Nozzle verstopt | PEEK gecarboniseerd | 450°C purge + koude trek |
| Barsten na print | Te snel afgekoeld | Langzamer afkoelen in printer |
| Stringing | Temp te hoog / retractie | Verlaag 5°C of verhoog retractie |

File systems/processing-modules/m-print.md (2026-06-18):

# Advanced Additive Manufacturing (M-PRINT)
## Chrystal Moon Base — Processing Module Concept

**Status:** Concept proposal — no hardware exists  
**Licence:** CC0

---

## Overview

**Input:** Metal powders and filaments — primarily aluminium (M-Aluminium) and silicon/ferrosilicon (M-Silicon, M-Iron); alumina ceramic (M-Ceramics); glass (M-Glass). Titanium only where imported stock is available (not a local Peary metal).

**Output:** Precision-manufactured components in metal, glass, and composites

**Process:** Laser powder bed fusion (LPBF) and directed energy deposition (DED) for metals; glass printing by extrusion or laser heating. These are established terrestrial additive manufacturing technologies being adapted for space environments.

**Note:** M-Print closes the manufacturing loop. Once M-Print is operational, the base can produce precision components — gears, brackets, optical mounts, electronic housings — from local materials. This is the beginning of true manufacturing independence from Earth.

**Key challenge:** Powder management in lunar gravity (1/6 g) and vacuum. Loose metal powder in low gravity and vacuum behaves very differently than in terrestrial manufacturing environments.

---

## Open Questions

1. What is the optimal processing rate for this module given the available power budget?
2. What is the module mass and volume, and does it fit within the planned delivery vehicle constraints?
3. What feedstock pre-processing is required before input to this module?
4. What are the failure modes and how are they detected and managed autonomously?
5. How does this module connect to the underground utility network for power, feedstock, and product output?

*Engineers with relevant process chemistry or ISRU experience are invited to review and improve this document via GitHub Issues.*

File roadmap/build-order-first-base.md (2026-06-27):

# Build Order — The First Base

**Status:** Concept proposal (the working sequence for the first base)
**Licence:** CC0
**Guiding principle:** *Slow but sure — op naar de volwassenheid.*

---

## The one rule that sets everything

**No human arrives until the base is fully finished.** The first base is built
entirely by autonomous robots. People come only when air, water, radiation
shelter, food, power, and the habitable spaces are all complete and proven. This
removes a whole class of risk (no humans living inside a half-built site) and it
resolves several design tensions on its own (see below).

---

## Where things land

The Pod and all cargo **land directly on the bare lunar surface**, exactly as every
lunar landing to date has done (Apollo, and the recent robotic landers). No prepared
pad, no landing platform, no titanium structure is required to land.

A **dust-free landing platform is a later upgrade**, not a precondition — it is
described separately (`dust-free-landing-platform.md`) and is parked for a later
phase. The first base does not need it.

---

## The sequence (high level)

1. **Land on bare regolith** at the Peary rim (north pole).
2. **Deploy the Pod** — mast, solar curtain, laser power, first robots.
3. **Sinter a floor** — robots fuse local anorthosite regolith into a load-bearing
   surface (this is the first physical structure; not a processing module).
4. **Dig and sinter underground** — corridors, rooms, storage, shelters, the
   utility network. **This is where people will actually live** (radiation makes
   underground the primary habitat — see `systems/life-support/radiation-protection.md`).
5. **Stand up the core processing** — oxygen, water (if local ice is confirmed),
   glass, aluminium (priority order in `systems/processing-modules/overview.md`).
6. **Build the domes — years later**, once the underground base exists. The glass
   domes are day-use spaces for work, farming, and recreation, **not** the primary
   living space (see the transparency-vs-shielding note in
   `systems/domes/dome-layer-architecture.md`).
7. **Verify everything** — only then do the first humans arrive.

---

## Why "underground first, domes later" is the right order

- **Radiation:** permanent living must be under mass (metres of regolith). The
  underground network provides that; transparent domes cannot.
- **It removes the dome material bottleneck from the critical path.** The dome
  reinforcement-fibre question (`dome-reinforcement-options.md`) does not block the
  first base, because domes come years after the corridors and rooms are dug and
  sintered. By the time domes are built, there may be years of test data — or even
  a separate production source — to draw on.
- **Psychology is handled by the "no humans until finished" rule.** Because nobody
  lives here during construction, there is no period of people living underground
  with no daylight; the first residents arrive to a completed base that already has
  its domes.

---

## What must be 100% complete before the first human

- Breathable atmosphere and its control loop
- Water supply and recycling
- Radiation shelter (underground) meeting a chosen dose target
- Food production running
- Power with margin through the dark periods
- Verified life-support redundancy

*(Which of these may keep growing after arrival vs. must be fully proven first is
itself a design decision — listed here as an open question, not yet fixed.)*

---

## How long will it take? — an honest non-answer

This document deliberately gives **no fixed build-time** for the first base. That is not
an oversight; it is the honest position.

Early attempts to estimate "how many years from first Pod to finished base" produced
wildly different answers depending on which assumptions went in — sintering speed,
recharge cycles, illumination uptime, how often robots need repair, how the real
anorthite highland material behaves. The spread was large enough that publishing any
single number would be inventing a certainty that does not exist.

So the sequence is built around **measured pace, not predicted pace**:

- The robots' very first task — sintering the Pod's bloom leaves to the regolith
  (`phase-0.2-the-pod.md`) — is also the first real measurement of how fast the system
  actually works on the Moon. Until that happens, every rate is an Earth-simulant guess.
- Each subsequent step (digging, sintering corridors, building rooms) produces more data.
  The base effectively **calibrates its own schedule as it builds.** A task that turns out
  twice as fast halves the estimate that follows it; a task that proves slow, or a robot
  that fails, stretches it.
- This fits the gated-growth model and the guiding principle: one step proven before the
  next, *slow but sure*. The timeline is an output of how well the system performs, not an
  input fixed in advance.

The honest summary: **the first base will take as long as it takes, and the estimate will
sharpen with every real task completed — starting with the very first leaf sinter.** A
firm schedule only becomes meaningful once there is lunar performance data to base it on.

---

## Open questions

1. What is the minimum "complete and proven" standard before the first crew?
2. The build-time itself is the biggest open question — see "How long will it take?"
   above. It cannot be answered honestly until early on-Moon tasks return real performance
   data.
3. Which subsystems are allowed to scale up after humans arrive, and which must be
   final beforehand?

*Engineers and mission planners are invited to review and improve this document.*

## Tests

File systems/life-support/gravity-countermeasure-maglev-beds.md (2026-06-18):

# Gravity Countermeasure — Maglev Sleeping Ring
## Chrystal Moon Base — Life Support Concept

**Status:** Concept proposal — novel application, no prototype exists  
**Author:** Berechja Kerkdijk  
**Licence:** CC0

---

## The Problem

The Moon's gravity is 1/6 of Earth's. Long-term exposure to low gravity causes:
- **Bone density loss** — the skeleton, unloaded by gravity, resorbs calcium
- **Muscle atrophy** — particularly postural muscles that normally work against gravity
- **Cardiovascular deconditioning** — the heart works less hard in low gravity
- **Fluid redistribution** — body fluids shift toward the head, causing vision problems and other effects

These effects are well documented from ISS data. Astronauts on the ISS (effectively 0g) lose 1–2% bone density per month without countermeasures. Exercise countermeasures on the ISS require 2 hours per day and are only partially effective.

For permanent lunar residents who never return to Earth, the long-term effects of 1/6g are unknown — but the trajectory from ISS data is concerning. A passive, automatic countermeasure that works during sleep — when residents are not doing anything else — is the most efficient possible approach.

---

## The Concept

A circular maglev track, built underground adjacent to the sleep habitat domes, carries individual sleeping pods rotating continuously to generate centrifugal "gravity" at the sleeping position. (The achievable g-level depends on radius and rpm — see Physics; the original 1 g claim was a calculation error.)

Residents sleep in their pod every night. Eight hours of partial-gravity loading on the skeleton and muscles (target g to be decided — see Physics), automatically, without any effort or time cost beyond normal sleep.

---

## Physics

Centrifugal acceleration: **a = ω² × r**

Where:
- a = target acceleration (9.81 m/s² = 1g)
- ω = angular velocity (radians/second)
- r = radius of the circular track to the sleeping position

**Corrected figures (the earlier table was wrong by ~3× in rpm).**
For 1 g (9.81 m/s²): rpm = (60 / 2π) × √(a / r).

| Track radius | Rotation for **1 g** | Rotation for **0.5 g** | Comfort note |
|---|---|---|---|
| 10 m | **9.5 rpm** | 6.7 rpm | far above the comfort limit |
| 15 m | **7.7 rpm** | 5.5 rpm | uncomfortable |
| 20 m | **6.7 rpm** | 4.7 rpm | uncomfortable for most |
| 30 m | **5.5 rpm** | 3.9 rpm | borderline |
| ~112 m | 3.0 rpm | 2.1 rpm | approaching comfortable, but huge tunnel |
| ~224 m | 2.1 rpm | 1.5 rpm | comfortable, but a ~450 m tunnel |

> **The hard trade — stated honestly.** The earlier claim that "20 m at 2.1 rpm
> produces 1 g" is wrong: 2.1 rpm at 20 m gives only **~0.10 g** — *less than the
> Moon's own 0.17 g*, i.e. useless as a countermeasure. Rotating-habitat research
> generally treats **≤ ~2 rpm** as comfortable for sleep and **> ~4–6 rpm** as
> likely to cause motion sickness. You cannot have all three of: comfortable rpm,
> a useful g-level, and a buildable radius. A true-1 g ring at comfortable rpm needs
> a radius around **200 m** (a ~450 m tunnel). A buildable ~20–30 m ring can only
> reach a useful g by spinning fast enough to make sleep difficult.
>
> **This needs a design decision (yours):** pick a realistic *target g* and accept
> the consequence — e.g. a modest partial-g ring at higher rpm, a large-radius ring,
> or dropping the sleeping ring in favour of the compression suit + resistance
> exercise (which carry no radius/rpm problem). Until that decision is made, treat
> the maglev sleeping ring as an **unproven concept with an unresolved geometry**,
> not a validated 1 g solution.

**Pod orientation:** The sleeping pod is oriented radially — feet toward the center of the circle, head toward the outside. Centrifugal force pushes the sleeper toward their feet (head end of the bed) — this is the correct orientation for simulating gravity. The sleeper lies on their back as normal, and feels pressed into the mattress at 1g.

---

## Why Maglev

The sleeping ring must rotate continuously for 8 hours every night. It must be:

- **Silent** — mechanical wheels on a track would make sleep impossible
- **Vibration-free** — vibration transmitted into a sleeping person is both uncomfortable and medically counterproductive
- **Maintenance-free over years** — no mechanical contact means no wear
- **Precisely speed-controlled** — the rotation rate must be stable to maintain the correct g-loading

Maglev is the only technology that meets all four requirements simultaneously. A sleeping ring on mechanical bearings would be impractical. Maglev makes it elegant.

---

## The Ring Structure

**Tunnel:** A circular sintered regolith tunnel, 20 metre radius, built underground adjacent to the sleep habitat dome cluster. Cross-section sufficient for the sleeping pod plus clearance. The tunnel is not pressurised to habitat standard — it is pressurised to a safe intermediate level, since the pods themselves are sealed.

**Track:** Maglev track runs around the inner circumference of the tunnel. Same standard as the base transport network.

**Pods:** Individual sleeping capsules — each carrying one person (or two for couples, in a wider pod). The pod is sealed, temperature-controlled, and comfortable. It has a small window so residents can see the tunnel passing if they wish, or the window can be opaqued for darkness. The pod connects to the base power and communication network during rotation — residents can receive calls or alarms even while sleeping.

**Capacity:** A 20-metre radius ring has a circumference of ~126 metres. At 3 metres per pod, approximately 40 pods can occupy the ring simultaneously — serving up to 40 residents per ring. Multiple rings can be built for larger populations.

---

## Entry and Exit

Residents enter and exit their pod while the ring is stationary or moving slowly. The ring slows to near-stop at a designated loading point, the pod opens, the resident enters, and the ring accelerates to operational speed. The acceleration is gradual — taking several minutes to reach 2.1 rpm — so residents are not subjected to sudden g-force onset.

The loading point connects directly to the underground network of the sleep habitat dome cluster. Residents walk from their dome, enter the loading point underground, board their pod, and sleep. They exit the same way in the morning.

---

## Combined Countermeasure Programme

The maglev sleeping ring is one element of a complete gravity countermeasure system:

| Period | Countermeasure | G-equivalent |
|---|---|---|
| Sleep (8 hrs) | Maglev sleeping ring | partial-g (target TBD) |
| Waking hours | Compression suit | Partial (20–60%) |
| Exercise (1 hr) | Resistance training | Variable |

Together, these three approaches aim to provide sufficient mechanical loading on the skeleton and cardiovascular system to prevent the worst effects of long-term 1/6g habitation. Whether this combined approach is sufficient is an open medical question that requires research — ideally on actual lunar residents, which is why the system needs to be built before the medical data exists.

---

## Open Questions

1. Is 2.1 rpm at 20 metre radius within the comfortable range for all residents, or will some people experience significant Coriolis-induced nausea that prevents sleep? Individual variation is significant.
2. What is the minimum nightly duration of 1g sleep required for meaningful bone and muscle preservation? 8 hours is assumed — this may be more or less than needed.
3. How does the sleeping pod maintain comfortable temperature and atmosphere during rotation? (The pod is sealed — CO₂ buildup during sleep is a specific concern.)
4. What is the power consumption of the maglev ring in continuous operation, and how does this fit in the base power budget?
5. Can the sleeping ring double as a medical centrifuge for therapeutic purposes — for example, treating residents showing early signs of bone density loss with extended high-g exposure?

Medical researchers, aerospace medicine specialists, and maglev engineers are specifically invited to engage with these questions.

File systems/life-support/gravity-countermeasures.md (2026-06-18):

# Gravity Countermeasures — Overview
## Chrystal Moon Base — Life Support

**Status:** Concept proposal  
**Licence:** CC0

---

## The Challenge

The Moon's gravitational acceleration is 1.62 m/s² — approximately 1/6 of Earth's 9.81 m/s². Long-term exposure to this reduced gravity causes measurable physiological deterioration in humans:

- **Bone density loss:** ~1–2% per month in 0g (ISS data). The 1/6g lunar environment will cause slower but still significant loss over years and decades.
- **Muscle atrophy:** Particularly postural muscles — those that normally work against gravity to keep us upright.
- **Cardiovascular deconditioning:** The heart works less hard; over time, cardiac muscle weakens.
- **Fluid redistribution:** Body fluids shift cephalad (toward the head), causing increased intracranial pressure, vision changes, and other effects.

For permanent residents who never return to Earth, the long-term consequences of 1/6g are unknown — ISS data covers months, not decades. CMB must design countermeasures based on the best available evidence while acknowledging this uncertainty honestly.

---

## Three-Layer Countermeasure System

CMB proposes three complementary countermeasures that together aim to provide sufficient mechanical loading to prevent the worst physiological effects:

### Layer 1 — Maglev Sleeping Ring (passive, nightly) — **geometry unresolved**
A circular maglev track carrying sleeping pods, intended to generate
centrifugal "gravity" at the sleeping surface during sleep. **Note:** the original
"20 m radius at 2.1 rpm = 1 g" figure was a calculation error — that combination
gives only ~0.10 g (less than lunar gravity). A real 1 g ring at a comfortable
rotation rate (~2 rpm) needs a radius near 200 m; a buildable ~20–30 m ring must
spin fast enough (~5–7 rpm) to risk motion sickness. A realistic *target g* must be
chosen, or this layer dropped in favour of Layers 2–3. Treat as an unproven concept
until resolved.

See GRAVITY-COUNTERMEASURE-MAGLEV-BEDS.md for the corrected physics and the trade.

### Layer 2 — Compression Suit (passive, daytime)
A thin elastic suit applying continuous axial and peripheral compression to the body during waking hours. Based on the Russian Penguin suit concept but updated with modern elastic materials and potentially pneumatic or shape-memory alloy elements. Target: 20–60% of 1g equivalent loading on the skeleton.

The compression suit is worn during normal work and daily activities — no additional time required.

See GRAVITY-COUNTERMEASURE-SUIT.md for full specification (document to be written).

### Layer 3 — Exercise Protocol (active, 1 hour daily)
Structured resistance exercise targeting the muscle groups most affected by low gravity — leg extensors, postural muscles, cardiovascular system. Equipment: resistance machines anchored to the floor (not free weights, which behave differently in 1/6g). Duration: 1 hour per day minimum.

This is the only countermeasure that requires deliberate time and effort from the resident. The other two layers are passive.

---

## Combined Target

| Period | Layer | Duration | G-equivalent |
|---|---|---|---|
| Sleep | Maglev ring | 8 hours | partial-g (TBD) |
| Waking — wearing suit | Compression suit | ~15 hours | 0.2–0.6g |
| Exercise | Resistance training | 1 hour | Variable, high |

Whether this combination is sufficient to prevent long-term physiological deterioration is an open medical question. It is the best available concept given current knowledge. Monitoring of resident health data over time will either validate the approach or indicate where it needs strengthening.

---

## Research Priority

The medical effectiveness of this combined countermeasure system is the most important health research question for CMB. Collaboration with aerospace medicine researchers — at ESA, NASA, JAXA, universities, and medical institutions — is specifically sought.

All health monitoring data from CMB residents (anonymised and with consent) will be published openly for the benefit of the broader field of space medicine.

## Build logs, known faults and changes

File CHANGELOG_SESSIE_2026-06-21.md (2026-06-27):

# Repository strengthening pass — 2026-06-21

Summary of all changes made in this session. Nothing here changes the project's
substance — it removes inconsistencies and adds verifiable sources.

## Phase 1 — Naming consistency
- Renamed `systems/robot-cmb-r1/` → `systems/robot-cmb8lf-l1/` (22 files).
- Removed duplicate `robot-cmb-r1-overview.md` (merged best line into overview.md).
- Updated 6 path references across README, roadmap, ai-and-monitoring, pod, sintering.
- Verified: 0 "robot-cmb-r1" / "CMB-R1" left in real files (only status report mentions it, correctly).

## Phase 2 — Number / fact consistency
- Crater diameter harmonised to **79 km** everywhere (sources vary 73–79 km; noted honestly).
- Latitude harmonised to **88.63°N** (was mixed 88.6 / 88.63).
- Founder location: "Sittard / Hegelsom" → **"Hegelsom, Limburg"**.
- Solar area math fixed: text said 2×9×30=540 but claimed 600 m². Corrected arm/film
  dimensions to ~10 m → 2×10×30 = **600 m²**, consistent with the 104/143 kW budget
  (fixed in both mast-solar-curtain.md and power-budget.md).
- Basalt → anorthosite: working-material references in the robot files changed to
  "molten regolith (anorthosite)" while KEEPING honest basalt-referenced temperature
  notes (~1,200 °C basalt-ref / ~1,550 °C anorthosite). Correct terrestrial basalt
  references (Hawaiian experiments, simulant analogues) deliberately left intact.

## Phase 3 — Sources added (files that had none)
- life-support/food-production.md — NASA hydroponics area (20–25 m² O₂, 50 m² food).
- life-support/medical.md — Earth–Moon delay corrected (~1.3 s one-way / ~2.6 s round-trip) + sourced.
- surface-access/decontamination-sequence.md — ESA/NASA lunar-dust toxicity sources.
- life-support/radiation-protection.md — references made clickable + secondary-particle
  nuance added (thin regolith barely helps vs GCR; 5 m needs Monte-Carlo confirmation).
- underground-network/emergency-shelters.md — sourced cross-reference (no duplication).
- domes/dome-printing-method.md — ESA 3D-printing / solar-sintering demonstrators.
- sintering/laser-sintering-physics.md — ESA confirms anorthite ~1,550 °C; simulant facts.

## Phase 3b — Plain-text references made clickable (in progress)
- foundation/location/illumination-data.md — 4 illumination papers as DOIs (Noda 89% confirmed).
- foundation/location/peary-crater-selection.md — illumination + ice (LCROSS, Li 2018 PNAS) DOIs.
- systems/processing-modules/m-mre-electrolysis.md — Schreiner DOI, MIT thesis, Blue Alchemist, NTRS.

## Phase 3b — Plain-text references made clickable (COMPLETED)
- All arXiv numbers across the repo auto-linked to arxiv.org/abs.
- All NASA NTRS numbers auto-linked to ntrs.nasa.gov/citations.
- foundation/location: illumination-data, peary-crater-selection, landing-and-precision-targeting,
  south-pole-alternative — Noda/Bussey/Mazarico/Smith/Speyerer&Robinson/Colaprete/Li 2018 as DOIs.
- processing-modules: m-mre-electrolysis (Schreiner DOI, MIT thesis, Blue Alchemist), m-silicon
  (US Patent, Landis DOI), m-oxygen (cross-ref).
- sintering: overview, demonstrator-1, energy-budget, laser-sintering-physics — Fateri & Meurisse DOIs.
- pod: mast-solar-curtain (Powalla CIGS DOI), laser-system, power-budget.
- domes: dome-printing-method (ESA), dome-reinforcement-options (3M Nextel).
- ~46 of 165 .md files now carry clickable, verified sources.

## Corrections made while sourcing (verification caught real errors)
- Fateri et al. (2019) journal fixed everywhere: was wrongly cited as "Scientific Reports",
  is actually *Journal of Aerospace Engineering* 32(6) — corrected in 4 files.
- "Fafaul et al." (GaAs receiver) could not be verified — likely a hallucinated citation from
  an earlier AI. Replaced with two verified sources (Algora et al. IEEE; NASA NTRS).
- Earth–Moon delay wording fixed (~1.3 s one-way / ~2.6 s round-trip, not "1.3–2.6 one-way").
- Radiation: added the honest secondary-particle nuance (thin regolith barely helps vs GCR).

## Status: COMPLETE — ready to push.

---

# Critical review pass (same day, later)

A second critical read-through to find things that needed better thinking. Findings and fixes:

## Removed unfounded figures
- **Phase 0 cost (€1.5–3M programme + €150–300k Demonstrator 1)** removed from all public
  texts (SUPPORT.md, roadmap/phase-0-earth/overview.md, media/technical-one-pager.md,
  media/pitch-one-pager.md). Replaced with honest "not yet fixed — a credible
  per-demonstrator breakdown still has to be worked out." (The detailed, sourced S1
  prototype BOMs in systems/CMB8LF_v1/ are real and were left fully intact.)

## Replaced false precision with honest framing
- **Build time of the first base:** added a "How long will it take? — an honest non-answer"
  section to roadmap/build-order-first-base.md. No fixed years claimed; the base
  calibrates its own schedule from real performance, starting with the first leaf sinter.
- **Leaf-sintering time (was "48–72 hours"):** rewritten in phase-0.2-the-pod.md as the
  project's first real-world pace measurement; no fixed duration claimed.
- **Robot battery autonomy (was "2–4 hours"):** softened to "a few hours, concept estimate
  pending Phase 0 validation" in chassis.md.

## Added missing justification
- **Why 16 robots:** added a note to systems/pod/overview.md — derived from 8 garages × 2
  robots, bounded by per-launch mass/volume; final fleet size is an engineering decision
  for a later phase. (Previously the number stood with no reasoning.)

## Status: critical pass COMPLETE.

---

# Deep verification pass (Opus 4.8, same day)

A third, deeper read-through specifically hunting for hidden contradictions, physics
errors, and unit problems. The repo proved remarkably consistent; only two real items found:

## Fixed
- **Solar constant inconsistency.** The repo used three different values (1,370 / 1,360 /
  1,357 W/m²) for the same physical constant. Harmonised to **~1,361 W/m² with the honest
  annual range (~1,321–1,413)** across all design files, with the note that on-site
  measurement gives the final figure. Power-budget results updated to ~103–104 / ~141–143 kW
  (rounded 104–143 kW band unchanged). Source citations that quote a specific value were
  left as-is.
- **"Built for all of humanity" → "For all of humanity"** (README, two BOM files,
  peary-deployment) — removed the past-tense suggestion that something is already built.

## Verified consistent (no change needed)
- Mast 35 m, 16 robots, 8 garages, power 104–143 kW, BSM heights 7/14/21/28/35 m, 600 m²
  solar — all consistent across the repo.
- Physical constants correct: lunar gravity 1.62 m/s², lunar night ~14.5 days, escape
  velocity ~2.373 km/s.
- Power outliers (280/200/130/108/103 kW) all legitimate: 280 = explicitly-flagged old
  value, 200 = flux per m², 130 = Horizon laser target, 108/103 = surplus within budget.
- Resident counts (500 city / 10 crew or pod / 40 per maglev ring) all in-context distinct.
- Battery & sintering kWh figures internally consistent and honestly flagged as uncertain.
- Nuclear power honestly addressed and rejected (no contradiction with solar-only design).
- All internal .md cross-references resolve; no broken links.

## Status: deep verification COMPLETE.

---

# Denkpunten-sessie aanpassingen (23 juni 2026)

Na een sessie van 10 kritische denkpunten zijn deze concrete repo-correcties gedaan:

## Communicatie naar aarde (data-relay-to-earth.md) — belangrijke correctie
- "From the near-side Peary rim, Earth is always visible" was te stellig. Gecorrigeerd:
  Peary ligt op de limb, Earth staat laag op de horizon, zichtbaar een groot deel van de
  tijd maar NIET gegarandeerd 100% (libratie + terrein kunnen line-of-sight onderbreken).
  Percentage moet met LOLA-topografie bevestigd worden (vgl. zuidpool ~50–93%).
- Twee onafhankelijke paden toegevoegd: directe pieklink (met data-buffering) + ESA
  relais (Lunar Pathfinder 2026 / Moonlight ~2030, een dienst — caveat: nu zuidpool-
  prioriteit, noordpool-dekking met ESA te bevestigen).
- Signaalvertraging gecorrigeerd: was "1.3–2.6 s one-way / 2.6–5.2 round-trip" (fout) →
  nu ~1.3 s one-way, ~2.6 s round-trip (consistent met rest van repo).

## Mast + bloom als twee harde mission-enders (mast-overview.md)
- Bloom-deployment toegevoegd als even-kritiek (mogelijk kritieker) faalpunt naast de
  mast: pod opent niet → robots opgesloten, geen herstelpad.
- 25-batterij-buffer per robot expliciet genoemd: tijdelijke mast-onderbreking
  overbrugbaar op eigen accu; alleen deployment-falen is onherstelbaar.
- Uitkomst van totale mislukking bewust open gelaten (hangt af van data die nog niet
  bestaat) i.p.v. een fictief reddingsscenario.

## Vertraging-consistentie (laser-communication.md)
- "2.6 to 5.2 seconds" round-trip (fout) → ~2.6 s round-trip, consistent gemaakt.

## Geverifieerd, geen wijziging nodig
- Stof-mitigatie via "sinteren voor de voet uit" stond al correct in leg-architecture.md
  (regel 128–132). Berechja's intuïtie klopte met bestaande tekst.

Volledige denkpunten-analyse: OPEN_DENKPUNTEN.md (werkdocument, 10 punten + sub-punten).

## Batterij-nodes uitleg (CMB8LF_v1 BOM v6 + vacuum)
- Verklarend kader toegevoegd bij "Segment Batterijen (25 nodes)": waar het getal 25
  vandaan komt (één node per bewegend segment, niet per poot), waarom (fault-tolerance:
  valt één node uit, werkt de rest), en dat 25 een schaalbare werkwaarde is — principe
  vast, exact aantal door engineering bepaald. Toegevoegd op verzoek: een vraag die bij
  review opkomt, zullen anderen ook stellen.

## Twee nieuwe robotklassen — concept (23 juni 2026)
Naar aanleiding van de "wielen vs poten"-discussie (oom's vraag) en de erkenning dat
transport en graven aparte taken zijn met aparte lichamen:
- **systems/robot-bobcat/README.md** — graver/dozer ("gerobotiseerde Bobcat"). Rol
  concreet (graven + egaliseren, werkt vóór de octopods uit, voedt ISRU), exacte specs
  expliciet voor professionals. Eigen klasse om fysieke reden (kracht vs stilstand), geen
  vierde specialist-octopod.
- **systems/robot-transport/README.md** — hauler op wielen over gesinterde paden.
  Kernidee: **standaard canister** (containerprincipe — elke machine koppelt dezelfde
  bak). Octopod-fallback expliciet (geen harde single-point dependency).

Principe vastgelegd: "geen specialisten" geldt BINNEN de octopod-bouwvloot; aparte klassen
(Bobcat, transport, cable-worm B1) zijn andere lichamen voor andere fysieke taken, elk met
redundantie-door-aantal. Exacte maten/aantallen wachten op prototype-metingen.

NB: alles valt onder "robots/drones van CMB"; definitieve plate-style naamgeving (type
direct afleesbaar uit de code) volgt later bij een complete hernoeming van de hele familie.

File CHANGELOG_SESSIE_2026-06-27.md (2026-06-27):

# Consistency pass — 2026-06-27

Summary of all changes made in this session. **No substance was added** — this pass
*removes obsolete information and resolves contradictions* that survived earlier targeted
scans, and records each removal here with the reason. The guiding rule for this session
(founder's instruction): *obsolete information must be removed, but noted in a changelog
with an explanation.*

Why these errors kept surfacing despite earlier scans: each previous scan was **targeted**
(it looked for one specific thing — a temperature, a battery figure, an Earth-visibility
claim). A targeted search for "1600 °C" cannot find a stray "13 modules." This session was
the first **full letter-by-letter read of all 169 files at once**, which is why traces from
several different older versions all surfaced together. The repo grew in layers over months;
correcting a core document sometimes left a reference deep in a one-pager or phase document
untouched, and occasionally a fix in file A exposed a now-inconsistent file B.

---

## 1 — Processing-module count harmonised to ~20

**Problem:** three different counts existed in the repo — "13 modules" (README, phase-1),
"22 modules" (horizon docs), while the actual `systems/processing-modules/` folder contains
**20** `m-*.md` files and the `overview.md` index lists 20.

**Fix (count verified by file count + index):**
- `README.md` — "13 processing modules" → "~20 processing modules".
- `roadmap/phase-1-foundation.md` — "13 processing modules" → "~20"; **also removed
  "titanium" from the list of locally-produced materials** (see §2).
- `horizon/HORIZON_ISRU_cable_network.md` and `horizon/_werkversie_NL/HORIZON_ISRU_kabelnetwerk.md`
  — "22 modules" → "~20 modules".

**Why "~20" and not a hard "20":** two of the twenty modules are explicitly *parked / not
viable at Peary* (`m-titanium`, `m-helium3`), so an approximate count is the honest framing.

---

## 2 — Titanium removed as a local product (highland-anorthosite correction)

**Problem:** leftover mare-composition assumptions still presented titanium / ilmenite as a
Peary resource, contradicting `PEARY-MATERIALS-REFERENCE.md` (Peary is highland anorthosite;
ilmenite is a mare mineral, effectively absent; ~0.4 wt% TiO₂).

**Fix:**
- `roadmap/phase-1-foundation.md` — removed "titanium" from local production; added a one-line
  note that ilmenite is absent at highland Peary and aluminium is the local structural metal.
- `media/vision-one-pager.md` — "Ilmenite bearing titanium" removed from "what might already
  be there"; rewritten to anorthosite/aluminium/calcium reality.

---

## 3 — "Earth continuously visible" softened (relay-backed)

**Problem:** `peary-crater-selection.md` still asserted Earth is *continuously* visible from
the Peary rim — the same over-strong claim already nuanced elsewhere
(`data-relay-to-earth.md`). Earth sits low over the polar horizon; libration and local terrain
can interrupt the direct line of sight.

**Fix (`foundation/location/peary-crater-selection.md`):**
- Criterion list: "continuous line-of-sight" → "line-of-sight a high fraction of the time
  (relay-backed for any gaps)".
- Earth-Visibility section rewritten: visible low on the horizon a large fraction of the time,
  not 100%; gaps covered by data buffering and a lunar relay satellite (ESA Lunar
  Pathfinder / Moonlight); exact % to be confirmed against high-resolution LOLA.
- **Left intact:** the equatorial "Earth always visible" line in `civilisation-blueprint.md`
  — that one is factually correct for the equatorial near-side and is not about Peary.

---

## 4 — Robot fleet: obsolete "8 robots / 32 swappable heads" model removed

**Problem — the biggest one.** Two robot philosophies co-existed in the repo:
- **Old (obsolete):** 8 robots that changed role by swapping one of **four physical heads**
  (sintering / thermal-buddy / bulldozer / watcher), 32 heads stored in the Pod.
- **Current:** **16 identical robots, everything integrated** (all sensors + sintering laser +
  infrared annealing), role set by **software task assignment**; only the two **heavy tools**
  (bulldozer blade, digger) are physically swapped, via the EPM arm interface.

The old model still lived in `swarm-logic.md`, `head-storage-in-pod.md`, `ai-onboard.md`, and
the four `head-*.md` files. This is the model the founder had already moved away from.

**Fix — obsolete model removed and replaced (per-file):**
- `systems/robot-cmb8lf-l1/swarm-logic.md` — Core Philosophy + Fleet + Dynamic Configuration
  rewritten from "8 robots / 32 heads / role-by-head-swap" to "16 robots / integrated /
  role-by-task-assignment"; an explicit *superseded* note added. "Monitors all 8 robots" → 16;
  "Pod head inventory" → heavy-tool & spare-parts inventory; Watcher "installs a replacement
  head" → installs a replacement leg/tool/module; open-question about head inventory rewritten.
- `systems/robot-cmb8lf-l1/head-storage-in-pod.md` — **fully rewritten.** Was "Tool Head
  Storage — 32 heads." Now "Spare-Parts & Tool Storage": the Pod is a depot for spare legs,
  spare integrated modules, heavy tools (blade/digger) and wear parts — not role-heads. A
  superseded banner explains the change.
- `systems/robot-cmb8lf-l1/ai-onboard.md` — "Head Operation: each head type has its own AI
  module" → "Tool and Task Operation": the AI runs the module for the assigned *task*; sensing
  and sintering are integrated, only blade/digger are swapped.
- `systems/robot-cmb8lf-l1/head-watcher.md` — retitled "The Watcher **Task**"; Role rewritten:
  the full sensor suite is integrated on every robot, so "Watcher" is a task the AI assigns,
  not a head. **Sensor-suite technical detail kept** — it is simply integrated, not detachable.
- `systems/robot-cmb8lf-l1/head-sintering.md` — retitled "Sintering (Integrated Function)";
  superseded banner: the sintering laser is integrated in the arm-legs, not a head; "leads a
  4-robot team" framing removed. Optics/process detail kept.
- `systems/robot-cmb8lf-l1/head-thermal-buddy.md` — retitled "Thermal-Buddy / Annealing
  (Integrated Function)"; banner: IR lamps are integrated on every robot (per-robot melt+anneal),
  "Thermal Buddy" is a broader-area *task*. Thermal detail kept.
- `systems/robot-cmb8lf-l1/head-bulldozer.md` — retitled "Bulldozer Task (Swappable Heavy
  Tool)"; banner: the blade is one of the two EPM heavy tools, not a role-head; "leads the
  construction team" removed. Grading detail kept.
- `systems/sintering/crack-prevention.md` — "Thermal Buddy robot applies IR heating" reworded
  to "every robot's integrated IR lamps … a robot assigned the broader-area Thermal-Buddy task".

> **Note on the `head-*.md` filenames:** the files are retitled internally but keep their
> `head-*.md` filenames for now (renaming files would break inbound links across the repo). A
> later naming-cleanup pass can rename them; the content is already corrected and each carries a
> superseded banner. The `README.md` "Previous concept (archived): four specialist robot types"
> note was already correct and was left as-is.

---

## 5 — Head position corrected: front (spider), not central-upper

**Problem:** `chassis.md` placed the tool head "centrally on the **upper** surface, not at the
front," and argued *against* a front mount. This contradicts the actual design — the robot is a
**spider** (the *8 Legged Freaks*; the S1 prototype's `DIMENSIONS_v2.md` states
"Vorm: Spin · achthoekig elliptisch" and the CAD is "Spider body"). The head sits at the
**front**, like a spider's prosoma.

**Fix (`systems/robot-cmb8lf-l1/chassis.md`):**
- Coupling-points list and "head attaches" sentence: head is at the **front**, on the same
  universal EPM coupling as the legs — **removable just like a leg** (founder's clarification),
  for repair or donor-harvesting.
- "Tool Head Position — Central Upper Mount" section **fully rewritten** to "Front (Spider
  Layout)" with a superseded banner explaining the old top-mount/360° argument is dropped.
- Clarified the brain/senses split: **head carries the sensors** (cameras, LiDAR, thermal,
  spectroscopy + working laser optics); **AI/compute lives in the body** (electronics bay).
  Earlier wording risked implying the AI sat in the head. The "Central upper section houses the
  main compute" line reworded to make clear the compute is in the body, distinct from the front
  head.
- **Added the founder's design rationale** for the split, so the *why* is on record: the head is
  the most exposed, moving, heat/dust-facing part, so putting critical hardware there would raise
  its failure rate and lose the hardware if the head is damaged/swapped; the body is the protected
  three-layer core, so the brain belongs there and the head is kept light, simple and cheap to
  replace (lose *eyes*, not *brain*). Also recorded that head mass is negligible vs the body, so a
  light pan/tilt head does not affect balance — it buys viewing/working angles at no cost to footing.

---

## 6 — Prototype brain: Raspberry Pi 5 → NVIDIA Jetson Orin Nano

**Reason:** the strategic brain runs the heavy AI (vision, SLAM, gait planning, sensor fusion,
the spectroscopy pipeline). The Jetson Orin Nano Super (~67 TOPS, 7–25 W) provides
GPU-accelerated inference far beyond the Pi 5. The layered architecture is unchanged —
**Jetson** (strategic) · **Pico W ×2** (CAN master + safety) · **RP2350 ×26** (per-segment
reflexes); CAN bus and moteus controllers untouched. One Jetson is bought for the prototype.

**Fix:**
- `systems/CMB8LF_v1/CMB8LF_v1_BOM_v6.md` — COMPUTE section: Pi 5 (€90) → Jetson Orin Nano
  Super 8GB (€249); MicroSD → NVMe M.2 SSD; peripheral "→ Pi5" labels → "→ Jetson"; rationale
  note added. Subtotal €284 → **€453**. Budget overview ROBOT TOTAAL €6.647 → **€6.815**,
  EINDTOTAAL €7.312 → **€7.497**. Top "kostenstructuur" block marked *indicative* and its
  compute line aligned (it never summed to the full total — pre-existing, now flagged).
- `systems/CMB8LF_v1/README.md` — "3-layer AI: Pi5 strategic" → "Jetson Orin Nano strategic";
  software file `pi5_main.py` → `jetson_main.py`; I2C/CAN pinout table "Pi5 …" → "Jetson …".
- `systems/CMB8LF_v1/SUPPLIER_MAILS_v6.md` — camera-interface line "Raspberry Pi 5" → "Jetson
  Orin Nano"; also fixed a licence claim ("open source (CC0/GPL)" → "open hardware CERN-OHL-S
  & open docs CC0", matching `LEGAL-STRUCTURE.md`).
- **Left as-is:** `SUPPLIER_MAILS_v5.md` (superseded older version; README points to v6).

---

## 7 — Software licence corrected in prototype README

**Problem:** prototype `README.md` stated "Software: GPL-3.0", contradicting
`LEGAL-STRUCTURE.md` and `software/README.md` (software is **proprietary**, kept in a separate
private repo).

**Fix (`systems/CMB8LF_v1/README.md`):** both the header licence line and the License section
changed to "Software: Proprietary (separate private repo)".

---

## 8 — Robot "head": integrated (head-less) direction opened for validation

**Not a correction — a design direction, recorded openly per the project's question-led
approach.** While reviewing the head, the founder questioned whether a "head" is a real
engineering need or a human/animal image projected onto a machine (a spider's head is fused
to its body; a car has none). The session worked through a **head-less, integrated** concept:
no separate head; brain deep in the body; *measuring ≠ seeing* (encoders for limb position,
thermal/spectroscopy for melt quality, LiDAR for mapping); targeted work-sensing between the
front legs; 360° awareness from distributed body sensors; and a live camera feed retained **for
the human override engineer**, not the robot (situation assessment, not real-time control, given
the ~2.6 s delay).

**Recorded as follows (leading with the new direction, old design kept visible):**
- New root document **`OPEN-DESIGN-INQUIRY-robot-head.md`** — lays out the trade-off and asks
  engineers to validate: is dropping the head right, or should we step back to the detachable
  head? Includes the unsolved sub-question of protecting the work-zone sensor from melt heat/glare.
- `systems/robot-cmb8lf-l1/chassis.md` — the head section now **leads with the integrated
  head-less direction** and references the earlier **detachable front-head** design as the
  fallback "under review"; the nine-coupling list updated to mark the front/head coupling as
  under review (may be dropped in the integrated design). Brain-in-body holds in both.
- The `head-*.md` files are **kept** (with their existing superseded banners) so the full
  decision history stays visible; they are not deleted.

**Deliberately not done:** the integrated concept is **not** propagated into all build/prototype
documents yet — it is a direction seeking validation, not a frozen decision. This matches the
founder's "laten bezinken / slow but sure" discipline.

---

## 9 — Complete head-less prototype variant created (`systems/CMB8LF_v1_HL/`)

**New parallel build, fully worked out so the design choice does not cost months later.** At the
founder's request, a complete head-less version of the CMB8LF-S1 prototype was created alongside
the standard one — *"so that if the choice is made, we already have it ready, including the
schematics and everything."*

**Scope of the difference:** only the **sensing/camera layer** changes. The working **laser-palm
stays in the front leg**; legs, chassis envelope, CAN bus, moteus, motors, Jetson brain, power,
gait and all motion firmware are **identical and shared** — the variant references the base files
instead of duplicating them, so the two cannot silently drift apart.

**Files created:**
- `systems/CMB8LF_v1_HL/README.md` — variant anchor + shared-vs-different table.
- `docs/HEADLESS_DESIGN.md` — full sensor-relocation spec (head → body), incl. deletion of the
  cosmetic "RGB eyes" and the pan/tilt mechanism, and the three work-window protection measures.
- `docs/DIMENSIONS_HL.md` — new sensor-position dimensions (delta to base).
- `CMB8LF_v1_HL_BOM.md` — delta BOM (−€34 removed, +€129 added → ~€7.592 total, ~€95 over base).
- `cad/CMB8LF_v1_HL_config.scad` — includes base config, adds sensor positions.
- `cad/CMB8LF_v1_HL_body_chassis.scad` — body with sensor recesses + LiDAR riser, 9th (head)
  coupling blanked.
- `cad/CMB8LF_v1_HL_sensor_mounts.scad` — body-integrated sensor/camera carriers (replaces
  `head_module.scad`).
- `diagrams/CMB8LF_v1_HL_Sensor_Layout.svg` — top + side view of every sensor position.
- `diagrams/CMB8LF_v1_HL_Wiring_Diagram.svg` — sensor-layer wiring (CSI/SPI/UART/I²C).
- `software/config_headless.py` — base config import with pan/tilt nodes removed + body sensor map.
- `software/sensors_headless.py` — sensor manager for body sensing + the human override feed.

**Cross-references added:** `systems/CMB8LF_v1/README.md` (points to the variant),
`OPEN-DESIGN-INQUIRY-robot-head.md` (notes the variant is fully built, not a sketch).

---

## Verification

After the pass, repo-wide greps confirm **0** remaining instances of: "13 modules",
"22 modules", "8 identical chassis / 32 heads" (outside superseded notes that quote them),
"Earth is continuously visible", "ilmenite bearing titanium", "Software: GPL" in the prototype
README, and "Pi5/Pi 5" in the active prototype docs (BOM_v6, README, SUPPLIER_MAILS_v6).
"16 robots / sixteen identical" now appears consistently.

**Not changed (out of scope, noted for a future pass):**
- The `head-*.md` files keep their filenames (internal titles corrected; rename later to avoid
  breaking links).
- A full "plate-style" rename of the whole robot family remains a deliberate later task.
- `SUPPLIER_MAILS_v5.md` left untouched as a superseded version.

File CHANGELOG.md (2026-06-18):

# Changelog — Chrystal Moon Base

## [Unreleased] — CMB8LF-S1 Revision 6

### CMB8LF_v1 — Complete Architecture Revision

**Breaking changes:**
- Complete redesign from hobby servos to brushless BLDC + moteus r4.11
- Power architecture: central LiPo → 25 distributed 6S nodes
- Control: PCA9685 PWM → CAN bus (1 Mbit/s, Canable USB adapter)
- Material: PC Space Grade → PEEK-CF (higher temp, lower outgassing)
- Gait: tripod → wave gait (maximum stability, 7 legs always grounded)
- Head position: top-mounted → between leg 1 and leg 2 (precision work)

**New features:**
- Bistable electromagnetic coupling ×9 (identical on all connection points)
- Si₃N₄ ceramic bearings throughout (vacuum-proof, no lubrication)
- MoS₂ dry film coating on all sliding surfaces
- Basalt exterior shields with quarter-turn click mount
- Aerogel thermal buffer between shield and structure
- Real laser sintering: 808nm/2W + 976nm/1W (not symbolic)
- Peary highland anorthosite simulant (corrected from mare basalt)
- 4-finger adaptive gripper: box grip / pincer / foot modes
- Distributed AI: Pi5 + Pico W ×2 + RP2350 ×24 + palm RP2350 ×2
- FSO laser communication (external) + CAN bus (internal)
- Wave gait implementation with work-stance lock
- Web dashboard on Pico W #2
- Spider geometry body: narrower at front and rear, widest in middle
- Distributed solar cells on femur segments + body rear
- Laser power receiving (GaAs cells, quadrant tracking) on head

**Software:**
- Complete rewrite: main_v6.py, config_v6.py, wave_gait_v6.py
- New: can_bus.py, moteus_ctrl.py, pi5_main.py
- New: rp2350_segment.py (×24 mini AI), laser_palm_v6.py
- New: safety_pico.py (Pico W #2)

**CAD:**
- New: vacuum_config.scad (central dimensions)
- New: leg_standard.scad (replaces leg_complete.scad)
- New: coupling_interface.scad (bistable magnetic)
- New: palm_laser.scad (laser palm + gripper)
- Rewritten: body_chassis.scad (spider geometry)
- Updated: head_module.scad (pan+tilt, between legs 1+2)

**Documentation:**
- BOM_v6.md (complete revision — all new hardware)
- PRINT_SETTINGS.md (PEEK-CF specific)
- VACUUM_PREP.md (updated protocols)

---

## [0.5] — BOM v5 (previous version)

- Power architecture: strict domain separation, dual 3S packs
- PTC fuses, E-stop, EMI ferrite cores added
- Prusament PC Space Grade as primary material
- CreatBot PEEK-300 as primary printer (Voron 2.4 / Intamsys as DIY alternatives)
- Tripod gait, PCA9685 servo control
- 650nm symbolic laser (visual effect only)

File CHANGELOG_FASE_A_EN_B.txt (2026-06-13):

CHANGELOG — Fase A consistentie + opschoning
Datum: 2026-06-13

## DUPLICATEN VERWIJDERD
- VERWIJDERD systems/pod/pod-overview.md (identiek aan systems/pod/overview.md)
- VERWIJDERD systems/robot-cmb-r1/robot-cmb-r1-overview.md (identiek aan systems/robot-cmb-r1/overview.md)

## VOLLEDIG HERSCHREVEN (achterhaalde configuratie)
- roadmap/phase-0.2-the-pod.md: 100m→35m mast, GaAs→CIGS, 880→600m², 280→104-143kW, 8→16 robots, PEEK→M55J CFRP, 10→5 segmenten, TRN-map met LOLA/altimetrie toegevoegd

## MEDIA ONE-PAGERS GECORRIGEERD
- media/technical-one-pager.md: 55m→35m, GaAs→CIGS, 880→600m², 280→104-143kW, laser 67.5→10-15kW, BSM-hoogtes, 8→16 robots, dome-goud thermisch, basalt→regolith/anorthosite, referentie Speyerer&Robinson(2005)→Bussey(2005)
- media/vision-one-pager.md: 55m→35m, 8→16 robots, GaAs→CIGS, 880→600m², 280→104-143kW, 'solid basalt'→glass-ceramic floor

## POWER + LOCATIE GECORRIGEERD
- systems/pod/mast-overview.md: power 129-177→104-143 kW, solar constant 1361→1370
- foundation/location/peary-deployment.md: kraterdiameter 73.1→79 km; illuminatie >90%→~89% (best peak, range 86-94%, eerlijke nuance 'geen 100%'); referentie Speyerer&Robinson(2005) gecorrigeerd naar juiste Bussey et al.(2005)+Noda(2008); 'sintered basalt roads'→sintered regolith (highland anorthosite)

## GOUD-FUNCTIE GECORRIGEERD
- systems/domes/dome-layer-architecture.md: Layer 3 functie 'Radiation reflection'→'Thermal/optical control'; eerlijke noot toegevoegd dat goud GEEN GCR-schild is (kan zelfs secundaire deeltjes geven). Overige goud-vermeldingen waren al correct (warmtefiltering/optisch).

## BASALT → ANORTHOSIET / REGOLIET (geologische correctie; Peary = hoogland)
- 'sintered basalt' → 'sintered regolith' globaal over 34 bestanden (structureel product, altijd correct)
- README, dome-layer Layer 1, peary-deployment roads, radiation shield, thermal buffers
- m-basalt.md: eerlijke feedstock-noot — basaltvezel vraagt mare-basalt; Peary-hoogland is anorthosiet (~1550°C smelt). Lokale optie = anorthosiet/mineraalvezel. GEFLAGD als vraag.

## GEFLAGD VOOR VRAGEN (echte techniek, niet auto-gecorrigeerd)
- Robot vorm/sinterfysica geparametriseerd op basalt (~1200°C); anorthosiet smelt ~1550°C → raakt laservermogen, vormtip-materiaal (W-Re/HfC), koelvenster. Mag NIET cosmetisch vervangen worden.
- 'basalt composite' robot-chassisarmor: materiaalkeuze bij hooglandfeedstock
- feasibility-analysis: 'Hawaiian basalt ~ highland regolith' analogie is chemisch discutabel (basalt mafisch vs anorthosiet felsisch)

## MAST/POWER RESTPUNTEN
- foundation/location/landing-zone-criteria.md: 100m mast → ~35m
- systems/sintering/energy-budget-per-m2.md: 880m²/67.5kW/13.5kW → ~600m²/~104-143kW systeem, ~10-15kW laser optisch (timelines proportioneel aangepast)

## LEGAL VOLLEDIG HERSCHREVEN
- LEGAL-STRUCTURE.md: CMB = open-source non-profit initiatief, GEEN aparte rechtspersoon, gedragen door Nexus Ignis B.V. (+ toekomstige robotica-entiteit). Eerlijke caveat: openheid = bedrijfsbeleid, niet onomkeerbare lock; reeds gepubliceerde open licenties zijn wél onherroepelijk. ANBI-noot. Geen winst op CMB; winst bij de BV's.
- LICENSE.md, LICENSE-HARDWARE.md, LICENSE-SOFTWARE.md: 'Stichting Chrystal Base' → 'Nexus Ignis B.V.' in attributie en IP-houderschap
- foundation/governance/overview.md: zero-tolerance statuten → 'founding principles'; Raad van Toezicht → company supervisory arrangement
- roadmap/phase-2-the-city/export-and-revenue.md + social-structure.md: revenue flow Stichting → commerciële entiteit/open initiatief

## NETTO RESULTAAT FASE A
- 2 duplicaten verwijderd (194→192 bestanden)
- Mast overal ~35m, power overal 104-143kW, solar overal CIGS/600m², robots overal 16
- Kraterdiameter 79km, illuminatie ~89% eerlijk, referentie Bussey gecorrigeerd
- Goud = thermisch/optisch (niet GCR-schild)
- 'sintered basalt' → 'sintered regolith' (34 bestanden); anorthosiet-correctie
- Legal volledig op Nexus Ignis B.V. constructie
- 3 echte techniek-punten GEFLAGD voor vragen (smeltfysica basalt 1200 vs anorthosiet 1550°C; chassis-armor; analogie)

==================================================
## FASE B — INHOUDELIJKE VERRIJKING
==================================================
1. systems/life-support/radiation-protection.md
   - NIEUWE sectie "Phased Shielding Depth": 5m gen-1 (volwassenen, ≤1jr, informed consent, geen kinderen) vs 10m+/lavatunnel voor permanente generaties; tabel; GCR bepaalt diepte, micrometeoriet+SEP gratis meegedekt
   - ISRU-constraint toegevoegd: waterstoflaag = water/ijs uit PSR (NIET geïmporteerd PE/LiH); gekoppeld aan geen-plastic regel; eigen watercircuit
   - NIEUWE alinea BNNT: anorganisch (geen plastic), boor vangt neutronen, TRL 3-4, voor kritieke dunne secties/import, niet bulk

2. foundation/location/landing-and-precision-targeting.md (NIEUW BESTAND, 80 regels)
   - Map-first-then-match strategie: laseraltimetrie (LOLA + eigen survey) → TRN tijdens afdaling
   - Onafhankelijke verificatie-flybys als bewuste redundantie (1 bron = 1 faalpunt; verse data; kosten verwaarloosbaar bij dit budget)
   - Sequence, open vragen, referenties (Bussey, Noda, LOLA, Mars2020 TRN)

3. foundation/location/landing-zone-criteria.md
   - NIEUWE sectie "Foundation — From Bearing to Levelling": draagkracht ≠ gelijkmatigheid; tilt/zetting bij 35m mast; geërodeerde rand = variabele draagkracht; gesinterde funderingsplaat (ISRU) als oplossing

## OPSCHONING
- 2 exacte duplicaten verwijderd (pod-overview.md, robot-cmb-r1-overview.md)
- systems/pod/archive/ BEWUST behouden (documenteert afgewezen ankerontwerpen — open science)
- Geen junk/lege/verouderde bestanden aangetroffen
- Telling: 143 markdown-bestanden; totaal 194 (begonnen 194, −2 duplicaten, +1 nieuw landingsdoc, +1 changelog)

==================================================
## VRAGENRONDE — UPDATES Q1-Q13 (sessie 13 juni)
==================================================
Q1  sintering/laser-sintering-physics.md: smelt basalt(~1200°C) vs anorthosiet(~1550°C) tabel + gevolgen (laser/tip/koeling); pointer-noten in robot README + thermal-buddy
Q1  +Open Questions laservermogen-toereikendheid (langere tijd vs upgrade vs pre-heating; fleet-brede koppeling)
Q2  chassis.md: 'basalt composite' → mineral-fibre composite met feedstock-noot; stray NL 'gevoelige'→sensitive gefixt
Q3  feasibility-analysis.md: Hawaiian-basalt~hoogland claim GECORRIGEERD (self-flagged) + echte hoogland-simulanten NU-LHT-2M/3M, EAC-1A
Q4  radiation-protection.md: Dose Target → compliance-met-alle-normen kader (NASA/ESA/ICRP/ALARA, 'meet or beat', strengste bij verschil)
Q5  radiation-protection.md: uitgebreide SEP-stormrespons (waarschuwingsketen 4 lagen, graded levels Watch/Warning/Evacuate/All-clear, evacuatie-architectuur, 6 open vragen)
Q6  mast-overview.md: lager-stofbescherming gekoppeld aan bloom-skirt+garages (3 lagen) + eerlijke open punten
Q7  laser-system.md: BSM line-of-sight strategie — hoogtevariatie + robot-relay/prism-concept + occlusiegrens (viewshed Phase 0)
Q8  NIEUW failure-modes-and-degradation.md: faalmatrix (laser/power/benen/vastzitten/head/sensor/comms/thermisch/batterij/totaal), 3 herstellagen, relay=nice-to-have
Q9  phase-0.2 + failure-modes: resupply NUCHTER ('mogelijk, niet aangenomen'; vloot 5-10jr zelfstandig)
Q10 crack-prevention.md: dual-laser annealing (smelt+anneal per robot) + Thermal Buddy koppeling + lange-termijn vloer-cycli als apart open punt; BSM-hoogtes robot overview 11/22/33/44/55→7/14/21/28/35
Q12 NIEUW ai-and-monitoring/cybersecurity.md: 4 lagen (fysiek/command-auth/hardware-binding/whitelist-default-deny), update-sleutel als kroonjuweel, open vragen
Q13 phase-0.2: opschaling 16→32→48→64 als nuchter scenario (niet baseline), 'promises only the floor'

## OVERSTATEMENT-SCAN: schoon — sterke woorden staan in eerlijke/ontkende context
## Eindtelling na Q-ronde: 145 markdown-bestanden (+2 nieuw: failure-modes, cybersecurity)

## DIEPE DUIK — CMB8LF_v1 printer/versie opschoning (sessie 13 juni)
- VERWIJDERD CMB8LF-v1-PRINT_SETTINGS.md (orphan, QIDI-printer, conflicteerde met v6)
- VERWIJDERD BOM_v5.md (vervangen door CMB8LF_v1_BOM_v6.md)
- VERWIJDERD SUPPLIER_MAILS_v5.md (vervangen door SUPPLIER_MAILS_v6.md)
- PRINT_SETTINGS.md: printer → CreatBot PEEK-300 primair; kalibratie gemarkeerd als opnieuw-te-valideren (QIDI/Voron-specifieke waarden vervielen)
- README.md spec-tabel + klipper-config noot → CreatBot primair, Voron/Intamsys DIY-alt
- BOM_v6 + BOM_vacuum: printer-opties → CreatBot primair, Voron/Intamsys als DIY-alternatief
- repo CHANGELOG.md: QIDI target → CreatBot PEEK-300
- shopping_list: CreatBot primair genoemd

## DIEPE DUIK — VERIFICATIE (alles schoon)
- Geen kapotte markdown-links
- Geen verwijzingen naar verwijderde bestanden
- Mast (~35m), power (104-143kW), solar (CIGS 600m²), robots (16) volledig consistent
- Resterende 55m/280kW correct gelabeld als 'earlier concept'; 10m mast = NASA VSAT-referentie (extern)
- Bewonersaantal 500 consistent (40 = maglev-ring capaciteit, legitiem)
- Overstatement-scan schoon (sterke woorden in eerlijke/ontkende context)
- Stof-op-panelen, mentale gezondheid, hibernatie, zwaartekracht-tegenmaatregelen: allemaal gedekt

## EINDTELLING
- 142 markdown-bestanden (3 verwijderd: orphan QIDI print-settings, BOM_v5, SUPPLIER_MAILS_v5)

## PRINTER-CORRECTIE (vervolg) — CreatBot PEEK-300 correct geplaatst
- FOUT HERSTELD: CreatBot stond abusievelijk als €699 'kan PEEK NIET printen' optie. Nu correct: primaire printer ~€14.999, print PEEK-CF direct
- Ingebouwde annealing toegevoegd: hete kamer doet in-situ annealing, geen aparte oven nodig (eerlijke nuance: hoogste kristalliniteit kan alsnog langere anneal vragen)
- Dubbele rationale: Nexus Ignis revenue-machine + prototype-bot printer; geen aparte oven = simpeler/goedkoper productieworkflow
- 'Waarom niet goedkoper': budgetmachines kunnen PEEK technisch maar niet verstandig; mislukte print kost meer dan betrouwbare machine
- Alternatieven (Intamsys/Voron/budget-non-PEEK) behouden als DIY-opties voor bijdragers
- BOM_v6 + BOM_vacuum beide consistent

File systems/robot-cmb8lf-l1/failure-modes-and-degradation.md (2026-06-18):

# Failure Modes and Graceful Degradation
## Chrystal Moon Base — CMB8LF-L1 Robot Fleet

**Status:** Concept proposal — failure strategy, not yet validated
**Licence:** CC0
**Last updated:** 2026

> A construction fleet operating for years on the Moon with no human hands on site will suffer failures. The design assumption is **not** that robots do not fail — it is that the fleet *degrades gracefully* instead of failing catastrophically. No single robot failure should stop construction, and most failures should be recoverable by the fleet itself. This document consolidates the failure scenarios and the layered response to each, building on the existing Watcher (`head-watcher.md`), head-swap (`head-attachment-mechanism.md`, `head-storage-in-pod.md`), and swarm-logic (`swarm-logic.md`) systems.

---

## The Three Recovery Layers

Every failure is handled by one or more of three layers, tried in order of preference:

1. **Self-recovery** — the robot detects its own fault and adapts (e.g. recomputes its gait after losing a leg, switches to a working head, retreats to a garage on its own power).
2. **Fleet repair** — a **Watcher** robot performs in-field assistance (decoupling a stuck leg, clearing debris, thermal diagnosis) or the robot returns to the Pod for a **head-swap**. The fleet has interchangeable heads and at least two Watchers precisely so this is possible without humans.
3. **Reassignment and quarantine** — if neither restores full function, the swarm AI reassigns the degraded robot to whatever task it can still perform, and redistributes its old work across healthy robots. A fully dead unit is parked clear of the work area as a parts donor.

The guiding principle: **a robot that cannot do its primary job is rarely useless — it is reassigned to a job it can still do.**

---

## Failure-Mode Matrix

The thresholds and recovery times below are concept-level and require Phase 0 validation. They are stated so the strategy is visible, not because the numbers are proven.

| Failure | Detection | First response | Fallback | Worst-case outcome |
|---|---|---|---|---|
| **Sintering laser fails** | Self-test + Watcher beam-quality check | Return to Pod, swap to a spare sintering head | If no spare head: reassign robot to non-laser work (dig, haul, sense) while another robot takes over its sintering | Construction rate drops slightly; robot still useful as bulldozer/hauler/Watcher-support |
| **Power receiver fails** (cannot take beamed power) | Charge-rate monitoring | Move to a better BSM line-of-sight; try relay from a neighbour | If still unpowered: drive on residual battery to nearest garage and dock for direct charge | Robot parked at garage until a receiver head/part swap; not lost |
| **One or more legs fail** | Onboard gait sensors; Watcher thermal/strain scan | AI recomputes gait for remaining legs (see `ai-gait-recalculation.md`) | Down to ~5 legs: continues on reduced gait. Below that: stationary tasks only (operate head in place) until Watcher assists | Immobile-but-working node, or towed to garage |
| **Stuck / mired in regolith** | Position vs commanded motion mismatch | Self free-ing routine (gait change, push-off) | Watcher approaches, clears regolith, decouples a jammed leg | Towed clear by Watcher; if unreachable, parked-in-place donor |
| **Head won't decouple / jammed interface** | Swap attempt fails | Watcher manipulates the coupling; dust-cover/EPM cycle | Robot keeps current head and is tasked to match it | Locked to one role until garage maintenance |
| **Sensor / Watcher-vision fault** | Cross-check against fleet data | Reassign sensing to another robot; degraded robot does brute tasks | Two Watchers mean one can cover the other's role | Reduced situational awareness, flagged to mission control |
| **Comms / laser-link loss** | Link-quality monitoring (pre-failure flagged early) | Switch BSM or relay via neighbouring robot's laser link | Autonomous safe-hold: stop, hold position, beacon, await contact | Temporary isolation, not damage |
| **Thermal overrun** (component overheating) | Watcher thermal imaging flags *before* failure | Reduce duty, move to shade, Thermal-Buddy assist | Power down the affected subsystem; continue on the rest | Early catch usually prevents hard failure |
| **Battery degradation / cell failure** | Capacity trend monitoring | Shorter work cycles, charge more often | Reassign to tasks near a garage / BSM | Reduced endurance, still productive |
| **Total robot failure** (no self-recovery, unreachable) | No response to fleet | Watcher attempts retrieval/tow | Parked clear of work zone | Becomes a **parts/material donor** — another robot can sinter replacement tiles or harvest components |

---

## Specific Notes

**Head-swap is the primary repair, by design.** Because heads (sintering, bulldozer, Watcher, digger, etc.) are interchangeable via the attachment mechanism, the single most common fix for a head-level failure is to return to the Pod and swap. Spare heads are stored in the Pod (`head-storage-in-pod.md`). This is cheaper and faster than recovering a whole robot.

**The Watcher is the fleet's surgeon — and there are two.** A single Watcher is a single point of failure for repairs, so the fleet carries at least two. One can operate on a patient robot while the other continues monitoring, or both can combine on a complex recovery. A Watcher can itself fail; in that case the fleet prioritises swapping a working head onto another robot to restore a second Watcher capability.

**The power-relay function is a "nice-to-have," not a dependency.** The robot-to-robot power relay described in `systems/pod/laser-system.md` (Layer 2) helps reach occluded robots — but if a robot's laser fails, it simply loses the *ability to act as a relay*, which is not a critical loss. No construction task is allowed to depend on a relay chain, exactly so that a laser failure degrades capability gracefully rather than breaking a power backbone.

**Robots are expendable; people are not.** During an SEP event or other hazard, robots are recalled where time allows, but the loss of a robot to a storm, a fall, or a mire is an accepted operational cost. The fleet is sized with this attrition in mind. Resupply via later Pods is **possible but not assumed** — the cadence is unknown and outside the project's control — so the fleet must survive on its own heads, spares, and in-field repair for the full operational life. Any resupply that arrives is a bonus, not part of the baseline.

---

## Open Questions

1. What is the realistic per-robot failure rate over a 5–10 year operational life, by subsystem, and does the planned fleet size (16 per Pod) absorb it?
2. How many spare heads of each type should each Pod carry, given expected failure rates?
3. What is the minimum healthy-fleet size below which construction effectively halts, triggering a resupply priority?
4. Can a robot reliably sinter replacement armour tiles or harvest components from a dead donor unit in field conditions? (Currently TRL 2 — aspirational; see `feasibility-analysis.md`.)
5. What autonomous decision logic governs when to repair in-field versus tow to garage versus abandon as a donor — and how is that decision logged for mission control?
6. How does the fleet behave if **both** Watchers are lost simultaneously, before a resupply?

*Engineers with fault-tolerant robotics, swarm-autonomy, or reliability-engineering experience are invited to review and improve this document via GitHub Issues.*

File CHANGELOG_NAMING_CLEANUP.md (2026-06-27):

# Naming cleanup — robot-cmb-r1 → CMB8LF-L1

**Date:** 2026-06-20
**Scope:** Repository-wide consistency pass on the lunar robot naming.

## Why

The repository had already moved to the **CMB8LF** naming scheme (S = Scale,
L = Lunar; e.g. CMB8LF-S1, CMB8LF-L1). The file *content* was already updated —
but the old `robot-cmb-r1` name survived in:
- the folder name `systems/robot-cmb-r1/`
- six path references pointing into that folder
- a leftover duplicate overview file

A reader (or an ESA reviewer) seeing both `CMB8LF-L1` in the text and
`robot-cmb-r1` in the paths would see two names for one robot. This pass removes
that inconsistency at the root.

## What changed

### Folder renamed
- `systems/robot-cmb-r1/`  →  `systems/robot-cmb8lf-l1/`
  (all 22 files inside preserved; their content already used "CMB8LF-L1")

### Duplicate removed
- Deleted `robot-cmb-r1-overview.md` (was a near-identical copy of `overview.md`).
  The single better-worded line from the duplicate — "...at ~7, 14, 21, 28, or
  35 m on the 35 m mast..." — was merged into the kept `overview.md`.

### Path references updated (6 files)
- `README.md` — repository-structure listing
- `roadmap/phase-0.2-the-pod.md`
- `systems/ai-and-monitoring/cybersecurity.md`
- `systems/ai-and-monitoring/overview.md`
- `systems/pod/laser-system.md`
- `systems/sintering/crack-prevention.md`

## What was deliberately NOT changed

- `WEBSITE-CORRECTION-STATUS.md` still contains the strings "CMB-R1 naming: none
  remain" and "CMB-R1 = 0". These are **correct** — that file is a status report
  *documenting* that the old name was removed. Editing them would falsify the
  record.

## Verification

- `grep` for `robot-cmb-r1` across all `*.md`: **0 results**.
- `grep` for `cmb-r1` / `CMB-R1` across all `*.md` outside the status report: **0
  results**.
- Robot folder now `systems/robot-cmb8lf-l1/` with all 22 files intact.
- No reference to the deleted duplicate remains.

## To commit

```
git add -A
git commit -m "Naming cleanup: robot-cmb-r1 -> CMB8LF-L1 (folder, paths, dedup)"
```

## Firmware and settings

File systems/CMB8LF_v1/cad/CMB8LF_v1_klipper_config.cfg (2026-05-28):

# ============================================================
# CMB8LF v1 — klipper_config.cfg
# Voron 2.4 + Phaetus Rapido HF 2 UHF
# PEEK-CF Print Instellingen
# CC0 · Chrystal Moon Base · 2026
# ============================================================
# WAARSCHUWING: PEEK vereist volle beschermingsmiddelen
# Dampen zijn schadelijk — zorg voor goede ventilatie
# Nozzle 400°C+ — brandgevaar — nooit zonder toezicht
# ============================================================

[printer]
kinematics: corexy
max_velocity: 200
max_accel: 2000
max_z_velocity: 15
max_z_accel: 350

[extruder]
# Phaetus Rapido HF 2 UHF — max 500°C
nozzle_diameter: 0.400
filament_diameter: 1.750
# PEEK-CF instellingen
control: pid
pid_kp: 28.5
pid_ki: 1.2
pid_kd: 170

[heater_bed]
# PEI vlak + Magigoo PC
control: pid
pid_kp: 68.0
pid_ki: 1.4
pid_kd: 820

# ── PEEK-CF PROFIEL ───────────────────────────────────────────
# Nozzle:    400°C (minimum) — gebruik 410°C voor zekerheid
# Bed:       110°C (Magigoo PC voor adhesie)
# Chamber:   min 55°C — liefst 80-100°C (PEEK crystallisatie)
# Fan:       UIT tijdens print (thermische scheur risico)
# Snelheid:  max 40mm/s (PEEK vloeit langzamer)
# Laagdikte: 0.15mm detail · 0.20mm structureel
# Infill:    Gyroid 40% (sterkte/gewicht optimaal)

[gcode_macro PEEK_CF_START]
gcode:
    M140 S110          ; bed temp
    M104 S410          ; nozzle temp
    M190 S110          ; wacht op bed
    M109 S410          ; wacht op nozzle
    M106 S0            ; ventilator UIT — cruciaal voor PEEK
    G28                ; home
    G1 Z5 F5000
    G1 X10 Y10 F3000
    G1 Z0.2 F1000
    ; Purge lijn
    G1 X100 Y10 E15 F800
    G92 E0

[gcode_macro PEEK_CF_END]
gcode:
    M104 S0            ; nozzle uit
    M140 S80           ; bed langzaam afkoelen (geen shock)
    G91
    G1 Z10 F3000
    G90
    G1 X0 Y300 F5000
    ; Laat langzaam afkoelen — minimaal 30 minuten
    ; Verwijder onderdeel PAS als bed onder 40°C is

# ── MATERIAAL NOTEN ───────────────────────────────────────────
# PEEK-CF outgassing: TML < 0.1% (Kimya / 3DXTech)
# Eerste laag adhesie: Magigoo PC op PEI, bed 110°C
# Krimping: ~1.2% — compenseer in CAD (schaal ×1.012)
# Na print: laat in gesloten printer afkoelen (min 1 uur)
# Vacuüm test: print is geschikt na >48u stabilisatie

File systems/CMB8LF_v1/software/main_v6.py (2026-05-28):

# ============================================================
# CMB8LF v1 — main.py v6
# Chrystal Moon Base · 8 Legged Freaks
# Volledig herschreven voor brushless CAN bus architectuur
# Platform: Raspberry Pi Pico W (×2) + Pi5 coördinatie
# CC0 · Berechja Kerkdijk · 2026
# ============================================================
# PICO W #1 — CAN MASTER (dit bestand)
#   - Wave gait coördinatie
#   - moteus commando's via CAN
#   - Sinter sequentie
#   - Ontvangt high-level commando's van Pi5 via UART
#
# PICO W #2 — SAFETY (apart bestand: safety_pico.py)
#   - E-stop bewaking
#   - Thermisch management
#   - Spanning bewaking
#   - Web interface
# ============================================================

import time
import asyncio
from machine import Pin, UART, I2C

# ── LOKALE MODULES ────────────────────────────────────────────
from config_v6   import (CAN_UART_TX, CAN_UART_RX, PI5_UART_TX,
                          PI5_UART_RX, LED_PIN, NODE_IDS, WAVE_ORDER,
                          WORK_POSITIONS, LIFT_HEIGHT, STEP_LENGTH)
from can_bus     import CANBus
from moteus_ctrl import MoteusController
from wave_gait   import WaveGait
from sinter_seq  import SinterSequencer

# ── HARDWARE INIT ─────────────────────────────────────────────
led = Pin(LED_PIN, Pin.OUT)

def blink(n=1, ms=120):
    for _ in range(n):
        led.on();  time.sleep_ms(ms)
        led.off(); time.sleep_ms(ms)

blink(3)
print("\n[BOOT] CMB8LF v1 — v6 Brushless CAN Architecture")
print("[BOOT] Pico W #1 — CAN Master · Wave Gait Controller")

# ── CAN BUS ───────────────────────────────────────────────────
# Canable USB-CAN adapter is verbonden met Pi5
# Pico W communiceert met Pi5 via UART (commando's)
# Alle moteus nodes zijn direct aangesloten op CAN bus via Pi5

print("[INIT] Pi5 UART link...")
pi5_uart = UART(0,
    baudrate=115200,
    tx=Pin(PI5_UART_TX),
    rx=Pin(PI5_UART_RX)
)
print("[INIT] Pi5 UART OK")

# ── MOTEUS CONTROLLERS ────────────────────────────────────────
# moteus r4.11 controllers worden aangestuurd via Pi5 CAN bus
# Pico W geeft commando's aan Pi5 die naar moteus stuurt
# Dit is de simplificatie voor het prototype:
# Pi5 draait moteus Python library direct

print("[INIT] Moteus node tabel laden...")

# Node ID schema: XY
# X = been (1-8), hoofd=9
# Y = positie (1=coxa/pan, 2=femur/tilt, 3=tibia, 4=palm AI)
MOTEUS_NODES = {}
for been in range(1, 9):
    for pos in range(1, 4):
        node_id = been * 10 + pos
        MOTEUS_NODES[node_id] = {
            "been": been,
            "pos":  ["coxa", "femur", "tibia"][pos - 1],
            "online": False,
            "pos_deg": 0.0,
            "torque_nm": 0.0,
            "temp_c": 0.0,
        }
# Hoofd
MOTEUS_NODES[91] = {"been": 9, "pos": "pan",  "online": False}
MOTEUS_NODES[92] = {"been": 9, "pos": "tilt", "online": False}

print(f"[INIT] {len(MOTEUS_NODES)} moteus nodes gedefinieerd")

# ── WAVE GAIT ─────────────────────────────────────────────────
gait = WaveGait(
    pi5_uart   = pi5_uart,
    nodes      = MOTEUS_NODES,
    wave_order = WAVE_ORDER,
    lift_mm    = LIFT_HEIGHT,
    step_mm    = STEP_LENGTH,
)

# ── SINTER SEQUENCER ──────────────────────────────────────────
sinter = SinterSequencer(pi5_uart=pi5_uart)

# ── COMMANDO PARSER ───────────────────────────────────────────
def parse_command(cmd: str) -> dict:
    """
    Parseer commando's van Pi5 (of laptop via Pi5).
    
    Formaat: COMMANDO:param1=val1,param2=val2
    
    Bekende commando's:
      STAND              — stabiele staande positie
      WALK:dir=1         — wave gait vooruit (dir=-1 achteruit)
      STOP               — stop gait
      WORK               — werkstand (alle gewrichten vergrendeld)
      SINTER:n=3         — sinter n lagen
      GRIP:mode=box      — grijper mode (box/pincet/voet)
      HOME               — alle gewrichten naar nulpositie
      STATUS             — stuur status terug
      NODE:id=11,pos=45  — stuur direct commando naar node
    """
    parts = cmd.strip().split(":")
    action = parts[0].upper()
    params = {}
    if len(parts) > 1:
        for p in parts[1].split(","):
            if "=" in p:
                k, v = p.split("=")
                params[k] = v
    return {"action": action, "params": params}

async def handle_command(cmd_dict: dict):
    action = cmd_dict["action"]
    params = cmd_dict["params"]

    if action == "STAND":
        await gait.stand()
        pi5_uart.write("OK:stand\n")

    elif action == "WALK":
        direction = float(params.get("dir", 1.0))
        asyncio.create_task(gait.walk(direction))
        pi5_uart.write("OK:walk\n")

    elif action == "STOP":
        await gait.stop()
        pi5_uart.write("OK:stop\n")

    elif action == "WORK":
        ok = await gait.work_stance()
        pi5_uart.write(f"{'OK' if ok else 'ERR'}:work\n")

    elif action == "SINTER":
        n = int(params.get("n", 1))
        asyncio.create_task(sinter.sinter_layers(n))
        pi5_uart.write(f"OK:sinter:{n}\n")

    elif action == "STATUS":
        online = sum(1 for n in MOTEUS_NODES.values() if n["online"])
        pi5_uart.write(f"STATUS:nodes={online}/{len(MOTEUS_NODES)}\n")

    else:
        pi5_uart.write(f"ERR:unknown:{action}\n")

# ── HEARTBEAT ─────────────────────────────────────────────────
async def heartbeat_task():
    while True:
        led.off()
        await asyncio.sleep_ms(50)
        led.on()
        await asyncio.sleep_ms(2950)  # 3 sec interval

# ── UART LUISTEREN ────────────────────────────────────────────
async def uart_listen_task():
    buf = ""
    while True:
        if pi5_uart.any():
            data = pi5_uart.read(64)
            if data:
                buf += data.decode("utf-8", "ignore")
                while "\n" in buf:
                    line, buf = buf.split("\n", 1)
                    if line.strip():
                        cmd = parse_command(line)
                        await handle_command(cmd)
        await asyncio.sleep_ms(10)

# ── STARTUP ───────────────────────────────────────────────────
async def startup():
    print("[STARTUP] Stand innemen...")
    await gait.stand()
    await asyncio.sleep_ms(500)
    blink(4)
    led.on()
    print("[READY] CMB8LF v1 operationeel")
    print("[READY] Wacht op commando's van Pi5")

# ── MAIN ──────────────────────────────────────────────────────
async def main():
    await startup()
    await asyncio.gather(
        heartbeat_task(),
        uart_listen_task(),
    )

try:
    asyncio.run(main())
except KeyboardInterrupt:
    print("\n[STOP] Handmatige stop")
    gait.emergency_stop_sync()
    led.off()
except Exception as e:
    print(f"[CRASH] {e}")
    import sys; sys.print_exception(e)
    blink(20, 50)
    led.off()

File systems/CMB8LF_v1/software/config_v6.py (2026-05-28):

# ============================================================
# CMB8LF v1 — config_v6.py
# Centrale configuratie voor brushless CAN architectuur
# CC0 · Chrystal Moon Base · 2026
# ============================================================

# ── GPIO PINS (Pico W #1 — CAN Master) ──────────────────────
LED_PIN       = 25
PI5_UART_TX   = 0    # GPIO 0 → Pi5 RX
PI5_UART_RX   = 1    # GPIO 1 → Pi5 TX
ESTOP_IN      = 14   # Van Pico W #2 (safety pico) via GPIO

# ── MOTEUS NODE IDs ───────────────────────────────────────────
# Schema: XY — X=been(1-8)/hoofd(9), Y=segment(1=coxa,2=femur,3=tibia,4=palm)
NODE_IDS = {
    # Been 1 — Grijper Links
    "been1_coxa":  11, "been1_femur": 12, "been1_tibia": 13, "been1_palm": 14,
    # Been 2 — Grijper Rechts
    "been2_coxa":  21, "been2_femur": 22, "been2_tibia": 23, "been2_palm": 24,
    # Benen 3-8 — Standaard
    "been3_coxa":  31, "been3_femur": 32, "been3_tibia": 33,
    "been4_coxa":  41, "been4_femur": 42, "been4_tibia": 43,
    "been5_coxa":  51, "been5_femur": 52, "been5_tibia": 53,
    "been6_coxa":  61, "been6_femur": 62, "been6_tibia": 63,
    "been7_coxa":  71, "been7_femur": 72, "been7_tibia": 73,
    "been8_coxa":  81, "been8_femur": 82, "been8_tibia": 83,
    # Hoofd
    "head_pan":    91, "head_tilt":   92,
}

# ── WAVE GAIT VOLGORDE ────────────────────────────────────────
# Spin-patroon: buiten → binnen, diagonaal afgewisseld
# Maximale stabiliteit op oneven terrein
WAVE_ORDER = [1, 5, 3, 7, 2, 6, 4, 8]
# Been 1+2 = grijpers (vooraan)
# Been 3+4 = voor-midden
# Been 5+6 = achter-midden
# Been 7+8 = achteraan

# ── GAIT PARAMETERS ───────────────────────────────────────────
LIFT_HEIGHT     = 35    # mm — ophefhoogte
STEP_LENGTH     = 40    # mm — staplengte
STEP_TIME_MS    = 380   # ms per stap (wave gait)
GAIT_SPEED      = 1.0   # 0.0-1.0 schaalfactor

# ── WERKSTAND POSITIES (graden van nulpunt) ──────────────────
# Spin-houding: breed uitgespreid, laag zwaartepunt
WORK_POSITIONS = {
    "been1": {"coxa": +35, "femur": -25, "tibia": +60},  # grijper voor-links
    "been2": {"coxa": -35, "femur": -25, "tibia": +60},  # grijper voor-rechts
    "been3": {"coxa": +55, "femur": +15, "tibia": +65},
    "been4": {"coxa": -55, "femur": +15, "tibia": +65},
    "been5": {"coxa": +55, "femur": +15, "tibia": +65},
    "been6": {"coxa": -55, "femur": +15, "tibia": +65},
    "been7": {"coxa": +35, "femur": +15, "tibia": +65},
    "been8": {"coxa": -35, "femur": +15, "tibia": +65},
}

# ── MOTEUS LIMITEN (graden) ───────────────────────────────────
JOINT_LIMITS = {
    "coxa":  (-75, +75),   # heup rotatie
    "femur": (-50, +70),   # knie/lifthoek
    "tibia": (-15, +95),   # enkel
    "pan":   (-95, +95),   # hoofd links-rechts
    "tilt":  (-45, +90),   # hoofd omhoog-omlaag
}

# ── MOTOR KOPPEL LIMIETEN (Nm) ───────────────────────────────
TORQUE_LIMITS = {
    "coxa":  3.0,   # GM5208-150T max cont. 3.5Nm
    "femur": 1.8,   # GM4108H-120T max cont. 2.0Nm
    "tibia": 0.7,   # GM3506-2 max cont. 0.8Nm
    "pan":   1.8,   # GM4108H
    "tilt":  0.7,   # GM3506-2
}

# ── THERMISCHE LIMIETEN ───────────────────────────────────────
TEMP_WARN_C   = 55    # waarschuwing
TEMP_CUTOFF_C = 70    # noodstop
PALM_TEMP_MAX = 65    # laserpalm max

# ── SPANNING LIMIETEN ─────────────────────────────────────────
SEGMENT_VOLT_MIN  = 18.0   # 6S lege cel (3.0V/cel)
SEGMENT_VOLT_WARN = 20.0   # 6S waarschuwing (3.33V/cel)
SEGMENT_VOLT_FULL = 25.2   # 6S vol (4.2V/cel)
BODY_VOLT_MIN     = 12.0   # 4S leeg
BODY_VOLT_FULL    = 16.8   # 4S vol

# ── WIFI ─────────────────────────────────────────────────────
WIFI_SSID     = "CMB8LF-v1"
WIFI_PASSWORD = "moonbase2026"
AP_MODE       = True
WEB_PORT      = 80

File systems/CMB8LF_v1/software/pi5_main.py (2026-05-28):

# ============================================================
# CMB8LF v1 — pi5_main.py
# Pi5 — Strategisch AI · Navigatie · CAN Brug
# Draait op Raspberry Pi 5 (Python 3.11+)
# Vereisten: pip install python-can asyncio
# CC0 · Chrystal Moon Base · 2026
# ============================================================

import asyncio
import serial
import json
import time
from can_bus     import CMBCANBus
from moteus_ctrl import LegController, HeadController

# ── HARDWARE INIT ────────────────────────────────────────────
print("[PI5] CMB8LF v1 — Pi5 Strategisch AI")
print("[PI5] Initialiseren...")

# CAN bus via Canable USB adapter
can_bus = CMBCANBus()
if not can_bus.connect():
    print("[PI5] CAN niet beschikbaar — check adapter")

# UART naar Pico W #1 (gait coördinatie)
pico1_uart = serial.Serial("/dev/ttyAMA0", 115200, timeout=0.1)
# UART naar Pico W #2 (safety)
pico2_uart = serial.Serial("/dev/ttyAMA2", 115200, timeout=0.1)

# Leg controllers
legs = {i: LegController(i, can_bus) for i in range(1, 9)}
head = HeadController(can_bus)

# ── STATUS ───────────────────────────────────────────────────
robot_state = {
    "mode":      "idle",      # idle/walk/work/sinter/emergency
    "legs":      {},
    "head":      {},
    "laser":     {"l1": False, "l2": 0.0},
    "battery":   {},
    "timestamp": 0.0,
}

# ── PICO W COMMUNICATIE ──────────────────────────────────────

def send_to_pico1(cmd: str):
    """Stuur commando naar Pico W #1 (gait master)."""
    pico1_uart.write(f"{cmd}\n".encode())

def send_to_pico2(cmd: str):
    """Stuur commando naar Pico W #2 (safety)."""
    pico2_uart.write(f"{cmd}\n".encode())

def read_pico(uart, timeout=0.05) -> str:
    """Lees respons van Pico W."""
    deadline = time.time() + timeout
    buf = ""
    while time.time() < deadline:
        if uart.in_waiting:
            buf += uart.read(uart.in_waiting).decode("utf-8", "ignore")
            if "\n" in buf:
                return buf.split("\n")[0].strip()
    return ""

# ── MODI ─────────────────────────────────────────────────────

async def mode_walk(direction: float = 1.0):
    """Activeer wave gait lopen."""
    if robot_state["mode"] == "work":
        await mode_idle()
    robot_state["mode"] = "walk"
    send_to_pico1(f"WALK:dir={direction:.1f}")
    print(f"[PI5] Lopen · richting={direction:.1f}")

async def mode_work():
    """Activeer werkstand — robot vergrendeld."""
    send_to_pico1("WORK")
    resp = read_pico(pico1_uart)
    if "OK" in resp:
        robot_state["mode"] = "work"
        print("[PI5] Werkstand ACTIEF")
        return True
    return False

async def mode_idle():
    """Stop en ga naar rust."""
    send_to_pico1("STOP")
    robot_state["mode"] = "idle"
    print("[PI5] Rust")

async def mode_sinter(n_layers: int = 1, palm: int = 1):
    """Activeer sinter sequentie."""
    if robot_state["mode"] != "work":
        print("[PI5] Eerst werkstand activeren")
        return False
    robot_state["mode"] = "sinter"
    send_to_pico1(f"SINTER:n={n_layers},palm={palm}")
    print(f"[PI5] Sinteren · {n_layers} laag/lagen · palm {palm}")
    return True

async def emergency_stop():
    """Noodstop — alles uit."""
    robot_state["mode"] = "emergency"
    send_to_pico1("ESTOP:all")
    send_to_pico2("ESTOP:all")
    can_bus.estop_all()
    print("[PI5] ⚠ NOODSTOP")

# ── STATUS VERZAMELEN ────────────────────────────────────────

async def update_status():
    """Verzamel status van alle subsystemen."""
    robot_state["timestamp"] = time.time()
    # Leg status via CAN
    for leg_id, leg in legs.items():
        robot_state["legs"][leg_id] = leg.status()
    # Head status
    robot_state["head"] = {
        "pan":  head.pan.status(),
        "tilt": head.tilt.status(),
    }

# ── COMMANDO ONTVANGEN (van laptop of autonoom) ──────────────

def parse_laptop_command(raw: str) -> dict:
    """Parseer JSON commando van laptop dashboard."""
    try:
        return json.loads(raw)
    except:
        return {}

async def handle_command(cmd: dict):
    """Verwerk binnenkomend commando."""
    action = cmd.get("action", "").upper()

    if action == "WALK":
        await mode_walk(float(cmd.get("dir", 1.0)))
    elif action == "STOP":
        await mode_idle()
    elif action == "WORK":
        await mode_work()
    elif action == "SINTER":
        await mode_sinter(
            int(cmd.get("layers", 1)),
            int(cmd.get("palm", 1)))
    elif action == "ESTOP":
        await emergency_stop()
    elif action == "LOOK":
        head.look_at(
            float(cmd.get("pan", 0)),
            float(cmd.get("tilt", 0)))
    elif action == "STATUS":
        await update_status()
        print(json.dumps(robot_state, indent=2))

# ── HOOFDLUS ─────────────────────────────────────────────────

async def main():
    print("[PI5] Opstarten...")
    # Wacht op CAN bus
    await asyncio.sleep(1)
    online = can_bus.scan_nodes(timeout=3.0)
    print(f"[PI5] {len(online)} CAN nodes online: {online}")

    # Hoofd naar centrum
    head.center()
    await asyncio.sleep(0.5)

    print("[PI5] ✓ Gereed")

    # Hoofdlus
    while True:
        await update_status()
        await asyncio.sleep(0.05)  # 20 Hz status update

try:
    asyncio.run(main())
except KeyboardInterrupt:
    print("\n[PI5] Gestopt")
    asyncio.run(emergency_stop())

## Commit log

2026-05-03 Create CHASSIS.md
    Add CMB-R1 chassis specification v0.1
2026-05-20 new details for the prototype robot soon to be build !
    [CMB8LF_v1_ambient_lighting.scad, CMB8LF_v1_arm_leg_combined.scad, CMB8LF_v1_body_chassis.scad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]
2026-05-28 CMB8LF v1 — Complete revision v6: brushless CAN architecture, distributed 24V power, real laser sintering, spectroscopic ISRU suite and full vacuum-rated design for Peary Crater demo.
    CMB8LF v1 is a 1:3.5 scale prototype of the CMB-R1 lunar
    octopod robot — the core technology demonstrator of the
    Chrystal Moon Base project (ESA OSIP qualified).
    The robot walks on 8 legs using wave gait (7 always
    grounded), sinters real regolith simulant using dual
    lasers (808nm + 976nm), and analyses material composition
    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
    [CMB8LF_v1_body_chassis.scad, CMB8LF_v1_coupling_interface.scad, CMB8LF_v1_head_module.scad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]
2026-06-07 Expand freshwater aquaculture; add energy/thermal foundation; extend radiation protection
    - dome-aquaculture-freshwater.md: full rewrite (64->193 lines). Adds 5-dome
    isolation rationale, basin geometry as open question, worked sizing estimate
    for ~500 residents with assumptions exposed, mouthbrooder reproduction,
    mineral supply (Earth + local by-products), purification automation limits,
    redundant circulation, water-filled-dome breach failure case. Sourced.
    - energy-and-thermal.md: new file. Peary illumination realism, robot vs base
    energy domains, fission reactor exclusion rationale, passive thermal strategy
    (basalt + water buffers), heating via circulating water (not the struc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
2026-06-07 Index energy-and-thermal; cross-reference pod power budget to base energy strategy
    - life-support/overview.md: add energy-and-thermal.md to the subsystem index table
    - pod/power-budget.md: note distinguishing the Phase 0.2 pod shadow protocol
    (robots hibernate) from the base-wide energy-continuity strategy for a
    populated base; cross-reference to life-support/energy-and-thermal.md
2026-06-13 Fix internal consistency across docs and rewrite legal structure
    - Unify mast (~35m), power (104-143kW), solar (CIGS/600m2), robot count (16) across all docs
    - Correct Peary data: 79km diameter, ~89% illumination, fix Bussey 2005 reference
    - Correct gold coating role to thermal/optical (not GCR shielding)
    - Replace "sintered basalt" with "sintered regolith" (Peary = highland anorthosite)
    - Rewrite legal structure: CMB as open-source non-profit under Nexus Ignis B.V.
    - Add phased radiation depth, ISRU shielding, landing strategy, foundation sections
    - Remove duplicate files
2026-06-13 Set CreatBot PEEK-300 as primary printer with built-in annealing rationale
    - CreatBot PEEK-300 as primary printer (~€14,999, prints PEEK-CF, built-in annealing = no separate oven)
    - Dual-purpose rationale: Nexus Ignis production/revenue machine + CMB8LF prototype printer
    - Cheaper machines retained as honest DIY alternatives for contributors
    - Removed stale files (BOM_v5, SUPPLIER_MAILS_v5, orphan QIDI print-settings)
    - Full consistency dig: links, values, overstatement all clean
2026-06-18 ChrystalMoonBase — fully corrected repository, 29-language website, growth-model and roadmap documents, and a complete, sourced processing-factory landscape for an autonomous highland (Peary) lunar b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
    A major correction-and-expansion package for the open-source Chrystal Moon Base project. All content reflects the highland/anorthosite ground truth at Peary (correcting the earlier mare-materials error) and follows two standing rules: ground every technical claim in cited sources, and minimise dependence on Earth. The repository fixes (materials, naming CMB8LF, one-B.V.-three-divisions legal structure, removed contradictions) and the 29-language website (all "basalt" terms corrected, Engli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
2026-06-19 Small consistency tweaks to the Chrystal Moon Base website and two roadmap docs: removed the duplicate founder introduction, and reframed the obsolete "four pods at once" deployment into the sequenti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
    Two minor corrections on top of the already-pushed repository. First, the Vision page introduced the founder twice ("I'm Berechja Kerkdijk, the founder…" followed by "My name is Berechja Kerkdijk. I am the founder…"); the redundant second self-introduction was removed so the personal text now flows from a single, humbler intro, better matching the page's own "Not a Race. A Collaboration." message. Second, the phased-out "four pods deployed at once" concept was reframed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
2026-06-20 Add HORIZON chapter: ISRU cable network + CMB8LF-B1 tunnel-mole
    New speculative far-future chapter, separated from the hard CMB pillars.
    Four energetically independent Pods on Peary's peaks of (near-)eternal light,
    linked by a self-healing communication mesh (no energy transport across the
    crater). On-site cabling: aluminium conductor (MRE/anorthite), glass/ceramic
    insulation (same regolith), laid underground by the new CMB8LF-B1 melt-boring
    tunnel-mole. Introduces robot class B (Bore/Burrow) alongside S (Scale) and
    L (Lunar). All claims sourced; physics honestly bounded in 3 feasibility
    categories. Includes 4 figures + Dutch working copy.
2026-06-21 Add Hybrid Radiation Shielding chapter to horizon/ (theoretical, open question)
    Expands the magnetic-shield exploration into a full hybrid concept: active
    superconducting magnet (bends charged GCR/SPE particles) paired with a passive
    layered dome (catches secondary neutrons the magnet cannot touch). Written
    explicitly as an open question, not a plan. Corrects an earlier over-optimistic
    draft: factor 2-3 dose reduction not 99%, ~380 mSv/yr surface dose not 165,
    secondary-particle penalty past ~45 g/cm2, YBCO fits Peary / MgB2 does not,
    unsolved ~20 GJ quench problem. 20 clickable verified sources. Updates horizon
    README to list both chapters.
2026-06-21 Critical review pass: remove unfounded figures, replace false precision with honest framing
    Removed the Phase 0 cost figures (1.5-3M programme + 150-300k Demonstrator 1) from
    all public texts - replaced with "not yet fixed, breakdown still to be worked out".
    Build time of the first base rewritten as an honest non-answer: the base calibrates
    its own schedule from real performance, starting with the first leaf sinter. Leaf
    sintering time and robot battery autonomy softened from hard numbers to Phase-0
    estimates. Added the missing justification for the 16-robot figure (8 garages x 2,
    bounded by launch mass/volume; final count is an engineering decision). Detailed S1
    prototype BOMs left fully in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
2026-06-27 Consistency pass + Jetson + spider-head + open head-inquiry + head-less variant — 27 June 2026
    Session 27 June 2026 — full-repo consistency pass plus a new complete prototype variant.
    Corrections (obsolete information removed, documented in CHANGELOG_SESSIE_2026-06-27.md):
    Processing-module count harmonised to ~20 throughout (was 13/22 inconsistently)
    Titanium removed as a local product (highland anorthosite — no ilmenite at Peary)
    "Earth continuously visible" softened to relay-backed line-of-sight
    Obsolete "8 robots / 32 swappable heads" model replaced by "16 robots, integrated, role by task assignment" (8 documents)
    Head position corrected to front/spider layout (was central-upper m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
    [CMB8LF_v1_HL_body_chassis.scad, CMB8LF_v1_HL_config.scad, CMB8LF_v1_HL_sensor_mounts.scad]
2026-07-10 Complete herschrijving van de cybersecurity-architectuur, met nieuwe stresstest
    cybersecurity-and-network-trust.md volledig herschreven van a tot z. Zeven verdedigingslagen (fysieke link, CCSDS 355.0-B-2 command-auth, NIST SP 800-193 firmware-vertrouwen, NIST SP 800-161 hardware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
    Nieuw: threat-scenario-analysis.md — 12-scenario red-team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
